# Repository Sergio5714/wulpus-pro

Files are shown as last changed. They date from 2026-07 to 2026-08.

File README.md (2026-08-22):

# WULPUS PRO
## A base platform for wearable ultra-low-power ultrasound
> Independent fork by @Sergio5714 (Sergei Vostrikov)

<p align="center">
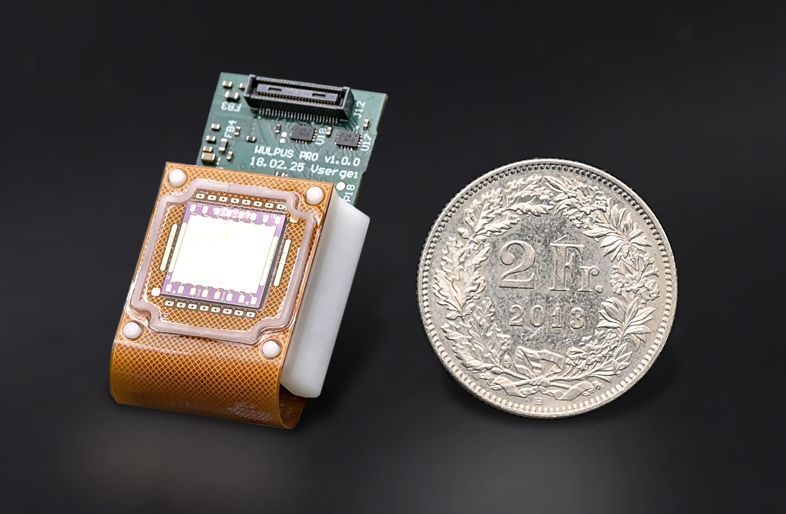
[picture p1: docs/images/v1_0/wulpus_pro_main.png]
WULPUS PRO main
  
  <br/>
  WULPUS PRO module with PolyCMUT transducer.
</p>

## Table of contents

- [Introduction](#introduction)
  - [System diagram](#system-diagram)
  - [Hardware photos](#hardware-photos)
  - [Specifications](#specifications)
- [Clone the repository](#clone-the-repository)
- [Structure of the repository](#structure-of-the-repository)
- [Documentation](#documentation)
- [Build Instructions](#build-instructions)
  - [PCBWay shared projects for WULPUS PCBs](#pcbway-shared-projects-for-wulpus-pcbs)
- [Usage](#usage)
  - [Wi-Fi setup: WULPUS PRO + XIAO ESP32-C6](#wi-fi-setup-wulpus-pro--xiao-esp32-c6)
  - [BLE setup: WULPUS PRO + nRF52 DK (legacy)](#ble-setup-wulpus-pro--nrf52-dk-legacy)
- [Citation](#citation)
- [Changelog](#changelog)
- [Authors](#authors)
- [License](#license)
  - [Limitation of Liability](#limitation-of-liability)

# Introduction

This repository contains the work in progress on the WULPUS PRO ultrasound platform, a successor of the [WULPUS Project](https://github.com/Sergio5714/wulpus). It features +30V unipolar programmable pulser, time-multiplexed multichannel acquisition frontend with TGC, optonal envelope extractor and support of PZTs and CMUTs. The module is compact (40 x 20 mm footprint) and lightweight (5g), allowing integration with external host PCB.

## System diagram

<p align="center">
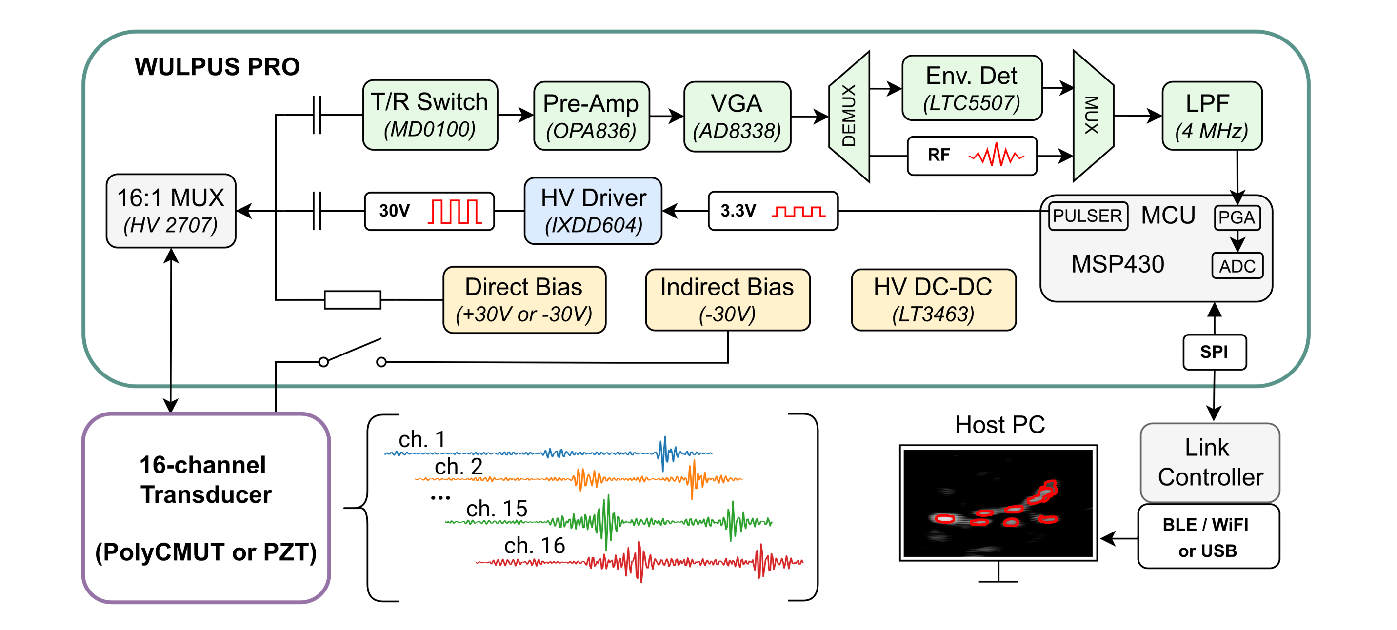
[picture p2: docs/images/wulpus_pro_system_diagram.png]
WULPUS PRO system diagram
  
  <br/>
  WULPUS PRO system diagram
</p>

## Hardware photos

<table>
  <tr>
    <td colspan="2" align="center">
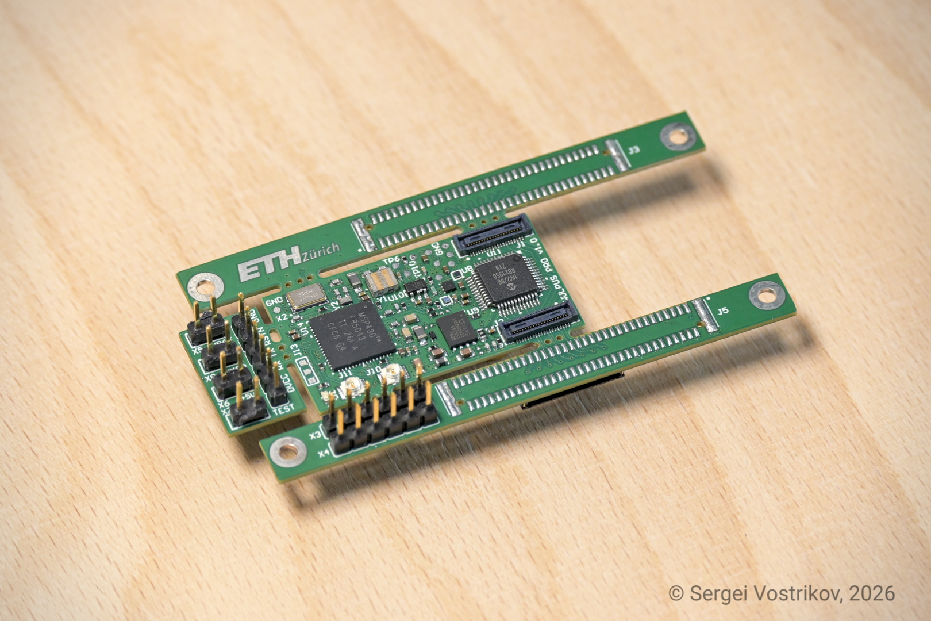
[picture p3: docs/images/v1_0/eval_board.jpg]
WULPUS PRO evaluation board
      
      <br/>
      WULPUS PRO evaluation board
    </td>
  </tr>
  <tr>
    <td width="50%" align="center">
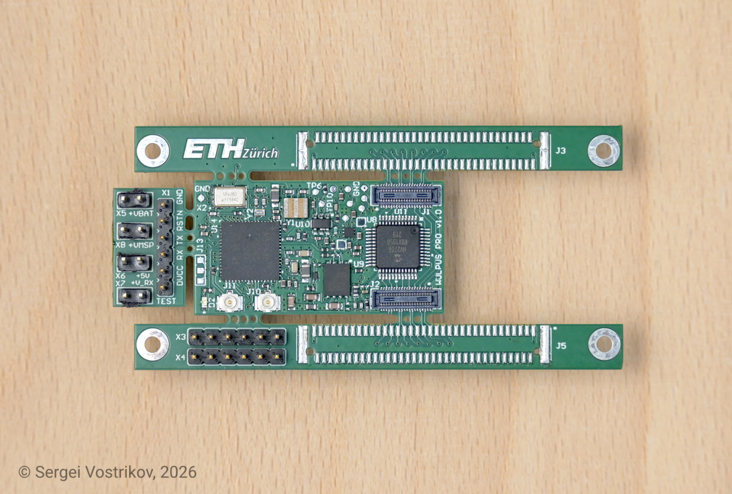
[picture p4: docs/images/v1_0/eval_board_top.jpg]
Top view of the WULPUS PRO evaluation board
      
      <br/>
      Top view
    </td>
    <td width="50%" align="center">
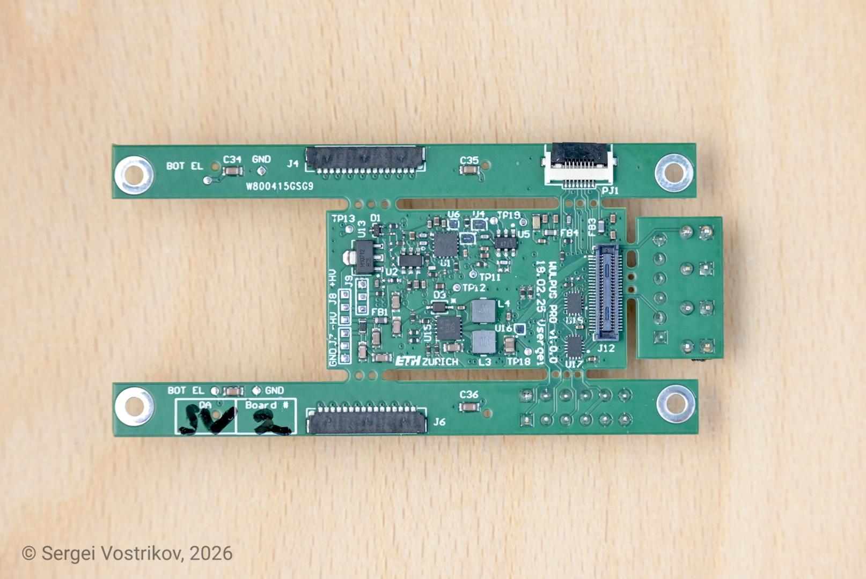
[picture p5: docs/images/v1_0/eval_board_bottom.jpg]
Bottom view of the WULPUS PRO evaluation board
      
      <br/>
      Bottom view
    </td>
  </tr>
</table>

## Specifications

WULPUS PRO builds on the original [WULPUS](https://github.com/Sergio5714/wulpus) platform and keeps the same low-power wearable ultrasound philosophy while extending the hardware and communication options. The table below compares the main features of WULPUS PRO with those of the original WULPUS platform.

| Feature | WULPUS | WULPUS PRO |
| --- | --- | --- |
| Number of channels | 8, time-multiplexed | **16**, time-multiplexed |
| Supported transducers | PZT transducers | PZT transducers, **CMUTs** |
| Excitation amplitude | 15 V unipolar | **30 V** unipolar |
| Excitation frequency | ~100 kHz to 4 MHz | ~100 kHz to **10 MHz** |
| Transducer biasing | - | Indirect or direct **bias**, **-30 V or 30 V** |
| Analog front-end | 10 dB LNA + 30.8 dB PGA | 6 dB LNA + **70 dB VGA** |
| TGC support | No (fixed gain) | **Yes** (linear profile) |
| Maximum PRF | 50 Hz | **300 Hz** |
| Power budget at 50 Hz PRF | <=25 mW | <=40 mW |
| Wireless link | BLE | BLE or **Wi-Fi** (via host) |
| Form factor | 46 x 25 mm footprint | **40 x 20 mm** footprint |

Full WULPUS PRO specifications are available in [docs/full_specifications.md](docs/full_specifications.md).

# Clone the repository

Clone the public repository without its private development submodule:

```bash
git clone git@github.com:Sergio5714/wulpus-pro.git
```

The `hw/kicad_us_lib` submodule is an internal development library hosted in a
private repository. External users do not have access to it and do not need to
initialize it to use the released fabrication outputs. For editing the KiCad
designs, generate project-specific symbol and footprint libraries from the
symbols and footprints embedded in the corresponding project files. See the
[hardware README](hw/README.md#internal-kicad-library) for details.

Authorized developers can initialize the private submodule after cloning:

```bash
git submodule update --init --recursive
```

# Structure of the repository

This repository has the following folders:

- `hw`, containing the CAD source files for:
  - WULPUS PRO acquisition PCB, located at `hw/wulpus_pro_acq_pcb_dev_board`
  - WULPUS PRO Wifi host PCB, located at `hw/wulpus_wifi_host_pcb`
  - optional WULPUS adapter PCB for polyCMUT transducers, located at `hw/wulpus_polycmut_adapter`; this board was developed for research purposes
- `fw`, containing the firmware source code, namely:
  - MSP430 ultrasound MCU firmware required for the WULPUS PRO module, located at `fw/msp430`
  - ESP32 Wi-Fi firmware for the Seeed Studio XIAO ESP32-C6, located at `fw/esp32`
  - nRF52 firmware, located at `fw/nrf52`:
    - nRF52832 DK board firmware, located at `fw/nrf52/ble_peripheral/US_probe_nRF52_firmware`
    - nRF52840 USB dongle firmware, located at `fw/nrf52/peripheral/US_probe_dongle_firmware`
- `sw`, containing the Python code for the WULPUS PRO API and graphical user interface
- `docs`, containing project-level documentation such as the full WULPUS PRO specifications

# Documentation

WULPUS PRO builds on top of the original WULPUS platform. Please refer to the original [WULPUS User Manual](https://github.com/Sergio5714/wulpus/blob/main/docs/wulpus_user_manual.pdf) for assembly instructions, example measurements, and GUI overview.

For WULPUS PRO-specific documentation, see:

- [Full specifications](docs/full_specifications.md)
- [Hardware README](hw/README.md)
- [MSP430 firmware README](fw/msp430/README.md)
- [ESP32 Wi-Fi firmware README](fw/esp32/README.md)
- [nRF52 BLE firmware README](fw/nrf52/README.md)
- [Software README](sw/README.md)

# Build Instructions

To build your own instance of the WULPUS PRO platform, complete the following steps:

1. *PCB manufacturing and assembly*<br>
   Use the design files, schematics, and bills of materials under the `hw` folder. The WULPUS PRO acquisition PCB is required. The polyCMUT adapter PCB is optional and intended for research setups using polyCMUT transducers.

2. *Flash the required MSP430 firmware*<br>
   The MSP430 ultrasound MCU firmware is required for the WULPUS PRO module. Follow the instructions in `fw/msp430` to set up the toolchain, compile the firmware, and flash the MSP430 MCU.

3. *Prepare a host system*<br>
   Choose one of the supported host interfaces:

   - ESP32-based Wi-Fi host, for example the Seeed Studio XIAO ESP32-C6. Follow the instructions in [fw/esp32/README.md](fw/esp32/README.md) to build and flash the ESP32 firmware. After flashing, complete the provisioning step so WULPUS PRO can connect to your Wi-Fi network.
   - nRF52 BLE host, using the nRF52832 DK board and nRF52840 USB dongle. This is the legacy BLE setup. Follow the instructions in [fw/nrf52/README.md](fw/nrf52/README.md) to compile and flash both firmwares.

   > **Note:** The new [WULPUS PRO WiFi host PCB](hw/wulpus_wifi_host_pcb) is currently undergoing testing
   > and will be integrated into the platform soon. It will support standard
   > Adafruit-compatible batteries for operation in WiFi mode, as well as
   > USB-only power and data streaming for WULPUS PRO. Until its integration is
   > complete, please use an external Seeed Studio XIAO ESP32-C6 module.

4. *Python dependencies installation on the host PC*<br>
   Follow the instructions in `sw` to install the Python dependencies. With `uv`, the basic setup is:

   ```bash
   uv sync
   uv run jupyter notebook
   ```

## PCBWay shared projects for WULPUS PCBs

For convenient one-click PCB production and assembly, you can use the PCBWay shared projects (optional; DIY via the `hw` folder is also supported):
- [WULPUS PRO Evaluation Board v1.0.0](https://www.pcbway.com/project/shareproject/WULPUS_PRO_Evaluation_board_v1_0_0_992d7510.html)

This option is convenient for outsourced PCB production and assembly, with an estimated **~1 month lead time** and a price of about **USD 220** per probe (evaluation board), based on mid-2026 pricing.

# Usage

## Wi-Fi setup: WULPUS PRO + XIAO ESP32-C6

1. Connect the ESP32 host module to the WULPUS PRO board using the pin mapping documented in [fw/esp32/README.md](fw/esp32/README.md).
2. Power the ESP32-based host module, for example the Seeed Studio XIAO ESP32-C6 running the firmware from `fw/esp32`.
3. Power the WULPUS PRO board through the connector or debug pin headers.
4. Start Jupyter from the `sw` folder:

   ```bash
   uv run jupyter notebook
   ```

5. Open `wulpus_pro_wifi_example.ipynb` in the browser and follow the notebook instructions for discovery, connection setup, configuration transfer, and acquisition.

## BLE setup: WULPUS PRO + nRF52 DK (legacy)

1. Connect the nRF52 DK to the WULPUS PRO board using the pin mapping documented in [fw/nrf52/README.md](fw/nrf52/README.md).
2. Plug in the USB dongle and power the nRF52 DK via USB.
3. Check the dongle connection. The green LED should light up. If it does not, press the reset button on the nRF52 DK and try again.
4. After confirming dongle connectivity, power the WULPUS PRO board through the connector or debug pin headers.
5. Start Jupyter from the `sw` folder:

   ```bash
   uv run jupyter notebook
   ```

6. Open `wulpus_pro_gui.ipynb` in the browser and follow the notebook instructions to begin acquisition.

# Citation

Please cite our [arXiv preprint](https://arxiv.org/abs/2607.12137):

```bibtex
@article{vostrikov2026wulpuspro,
  title={WULPUS PRO: Multi-mode Ultra-Low-Power Wearable Ultrasound and Array Imaging with CMUT Support},
  author={Vostrikov, Sergei and Villani, Federico and Hirschi, Cedric and Lu, Jinhao and Welsch, Jonas and Angerer, Martin and Cretu, Edmond and Rohling, Robert and Cossettini, Andrea and Benini, Luca},
  journal={arXiv preprint arXiv:2607.12137},
  year={2026},
  url={https://arxiv.org/abs/2607.12137}
}
```

If you would like to cite this repository, please use:

```bibtex
@misc{wulpus_pro_repo_sergio5714_2026,
  title={WULPUS PRO: A Base Platform for Wearable Ultra-Low-Power Ultrasound (Independent Fork)},
  author={Vostrikov, Sergei and Villani, Federico and Hirschi, Cedric and Cossettini, Andrea and Benini, Luca},
  year={2026},
  howpublished={GitHub repository},
  url={https://github.com/Sergio5714/wulpus-pro}
}
```

# Changelog

See [CHANGELOG.md](CHANGELOG.md) for release notes and main project changes.

# Authors

This fork is maintained independently by @Sergio5714 ([Sergei Vostrikov](https://scholar.google.com/citations?user=a0KNUooAAAAJ&hl=en)).

The WULPUS PRO system was originally developed at the [Integrated Systems Laboratory (IIS)](https://iis.ee.ethz.ch/) at ETH Zurich by:

- [Sergei Vostrikov](https://scholar.google.com/citations?user=a0KNUooAAAAJ&hl=en) (PCB design, firmware, software, open-sourcing)
- [Federico Villani](https://scholar.google.com/citations?user=5LgLMCEAAAAJ&hl=en) (PCB design, component selection)
- [Cedric Hirschi](https://www.linkedin.com/in/c%C3%A9dric-cyril-hirschi-09624021b/) (firmware, software)
- [Andrea Cossettini](https://scholar.google.com/citations?user=d8O91jIAAAAJ&hl=en) (supervision, project administration)
- [Luca Benini](https://scholar.google.com/citations?hl=en&user=8riq3sYAAAAJ) (supervision, project administration)

Thanks to all the people who contributed to the WULPUS PRO platform:

- [Sebastian Frey](https://scholar.google.com/citations?user=7jhiqz4AAAAJ&hl=en), ETH Zürich (design review)
- [Alfonso Blanco Fontao](https://www.linkedin.com/in/alfonso-blanco-fontao-b6214726/), ETH Zürich (design review, PCB fabrication coordination)
- [Ciara Giles Doran](https://www.linkedin.com/in/ciaragilesdoran/) (preliminary evaluation of the AD8338 VGA)

# License

The following files are released under Apache License 2.0 (`Apache-2.0`) (see `sw/LICENSE`):

- `sw/`

The hardware designs are released under Solderpad v0.51 (`SHL-0.51`):

- `hw/`

See the [hardware license table](hw/README.md#license) for the applicable license file and copyright holder for each PCB design.

The `fw/msp430/`, `fw/nrf52/`, and `fw/esp32/` directories contain third-party sources that come with their own licenses. See the respective folders and source files for the licenses used.

## Limitation of Liability

In no event and under no legal theory, whether in tort (including negligence), contract, or otherwise, unless required by applicable law (such as deliberate and grossly negligent acts) or agreed to in writing, shall any Contributor be liable to You for damages, including any direct, indirect, special, incidental, or consequential damages of any character arising as a result of this License or out of the use or inability to use the Work (including but not limited to damages for loss of goodwill, work stoppage, computer failure or malfunction, or any and all other commercial damages or losses), even if such Contributor has been advised of the possibility of such damages.

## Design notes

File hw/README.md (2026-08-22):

# WULPUS PRO PCB design files

This directory contains the PCB designs used by WULPUS PRO. The source files are
provided in Altium Designer or KiCad format, depending on the board. Where
available, each project also includes PDF schematics and assembly drawings under
`docs`, and production-ready files under `fabrication_outputs`, including bills
of materials, Gerber files, NC drill files, and pick-and-place files.

## Included PCB designs

### WULPUS PRO acquisition board

Directory: [`wulpus_pro_acq_pcb_dev_board`](wulpus_pro_acq_pcb_dev_board)

The main WULPUS PRO ultrasound acquisition and pulser board. This board contains
the transmit and receive signal paths, high-voltage switching, power supplies,
MSP430 control circuitry, and the host interface. The design sources are provided
in Altium Designer format. This board is required to build a WULPUS PRO system.

### WULPUS PRO Wifi host

Directory: [`wulpus_wifi_host_pcb`](wulpus_wifi_host_pcb)

A dedicated wireless host board for WULPUS PRO, based on the Seeed Studio XIAO
ESP32-C6. It connects to the acquisition board and runs the ESP32 firmware in
[`../fw/esp32`](../fw/esp32), providing Wi-Fi control and data transfer. The
design sources are provided in KiCad format, together with fabrication and
assembly outputs.

### polyCMUT adapter board

Directory: [`wulpus_polycmut_adapter`](wulpus_polycmut_adapter)

An optional research adapter for connecting polyCMUT transducers to WULPUS. The
design sources are provided in Altium Designer format. This board is not required
for standard WULPUS PRO operation.

## Internal KiCad library

The [`kicad_us_lib`](kicad_us_lib) directory is referenced as a Git submodule and
contains the internal KiCad symbols, footprints, and related library assets used
to develop the hardware designs. It is hosted in a private repository and is
intended only for internal development; external users will not have access to
it. The library could not be made publicly open source because some of its
contents are subject to third-party licensing restrictions.

The released KiCad projects embed the symbols and footprints used by each
design. External users are advised to generate their own project-specific symbol
and footprint libraries from the corresponding project files instead of relying
on `kicad_us_lib`. The released fabrication outputs can be used without the
private submodule.

## PCBWay shared projects

For convenient one-click PCB production and assembly, you can use the PCBWay shared projects (optional; DIY using the design and fabrication files in this folder is also supported):

- [WULPUS PRO Evaluation Board v1.0.0](https://www.pcbway.com/project/shareproject/WULPUS_PRO_Evaluation_board_v1_0_0_992d7510.html)

This option is convenient for outsourced PCB production and assembly, with an estimated **~1 month lead time** and a price of about **USD 220** per probe (evaluation board), based on mid-2026 pricing.

## License

All three PCB designs are released under the Solderpad Hardware License v0.51
(`SHL-0.51`). They use separate license files because their copyright holders
differ:

| PCB design | Directory | License file | Copyright |
| --- | --- | --- | --- |
| WULPUS PRO acquisition board | [`wulpus_pro_acq_pcb_dev_board`](wulpus_pro_acq_pcb_dev_board) | [`LICENSE_ETH`](LICENSE_ETH) | Copyright (C) 2025 ETH Zurich. All rights reserved. |
| WULPUS polyCMUT adapter | [`wulpus_polycmut_adapter`](wulpus_polycmut_adapter) | [`LICENSE_ETH`](LICENSE_ETH) | Copyright (C) 2025 ETH Zurich. All rights reserved. |
| WULPUS PRO Wifi host | [`wulpus_wifi_host_pcb`](wulpus_wifi_host_pcb) | [`LICENSE`](LICENSE) | Copyright (C) 2026 Sergei Vostrikov. All rights reserved. |

The license terms are otherwise identical. The internal `kicad_us_lib`
submodule contains third-party material and is not covered by this table; its
contents retain their respective license terms.

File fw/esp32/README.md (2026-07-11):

# WULPUS PRO source files for ESP32 firmware project

This firmware enables WULPUS PRO to connect to Wi-Fi via a ESP32-C6, which enables higher throughputs and thus framerates.

The firmware includes the following features:
- **mDNS**: Multicast DNS for local network discovery
- **Full integration with the Python API**: The firmware also comes with an extension to the Python API, which allows you to control the WULPUS PRO over Wi-Fi
- **Power Management**: The firmware includes power management, which allows the ESP32 to enter light sleep when not in use. This results in ~1.5mA current draw
- **Easy expandability**: The firmware is designed to be easily extensible, allowing you to add new features and functionality as needed

# How to get started?

This firmware is written with [ESP-IDF](https://github.com/espressif/esp-idf). We recommend using at the official [VS Code extension](https://github.com/espressif/vscode-esp-idf-extension/tree/master).

The firmware has been tested on both the [ESP32-C6-DEVKITM-1](https://docs.espressif.com/projects/esp-dev-kits/en/latest/esp32c6/esp32-c6-devkitm-1/user_guide.html) and the [Seeed Studio XIAO ESP32-C6](https://wiki.seeedstudio.com/xiao_esp32c6_getting_started/) boards. The XIAO ESP32-C6 target is expected to receive longer-term support, while the DevKit remains useful for development and bring-up. The firmware should work on other ESP32-C6 boards with suitable board defaults, and is designed to be portable to other ESP32 boards as well.

### Board Variants

Board-specific pinouts are stored as ESP-IDF defaults files under `boards/`. Keep reusable project settings in `sdkconfig.defaults`, chip-level settings in `sdkconfig.defaults.<target>`, and board pin choices in the board file.

To configure the firmware for the Seeed Studio XIAO ESP32-C6:

```powershell
idf.py -D SDKCONFIG_DEFAULTS="sdkconfig.defaults;sdkconfig.defaults.esp32c6;boards/xiao-esp32c6.defaults" reconfigure
```

To configure the firmware for the ESP32-C6-DEVKITM-1:

```powershell
idf.py -D SDKCONFIG_DEFAULTS="sdkconfig.defaults;sdkconfig.defaults.esp32c6;boards/esp32c6-devkitm-1.defaults" reconfigure
```

After reconfiguring, build and flash as usual:

```powershell
idf.py build
idf.py -p COM7 flash monitor
```

Adapt `COM7` to the serial port assigned to your ESP32 board.

### IMPORTANT: Provision Wi-Fi after flashing

After flashing the firmware for the first time, provision the ESP32-C6 with the Wi-Fi network credentials. Provisioning lets the ESP32 store the SSID and password in non-volatile memory, so the firmware can reconnect to the same network after reset or power cycling.

Follow Espressif's provisioning documentation for the first-time setup flow: [ESP-IDF Provisioning API](https://docs.espressif.com/projects/esp-idf/en/stable/esp32c6/api-reference/provisioning/index.html).

### Connection to WULPUS PRO

Use the following default pin mappings to connect the WULPUS PRO acquisition board to the ESP32-C6 board.

Seeed Studio XIAO ESP32-C6:

| **Signal** | **ESP32-C6 GPIO** | **XIAO ESP32-C6 Pin** | **WULPUS PRO Connector Pin** |
|---|---|---|---|
| `SPI_SS` | 21 | D3 | X3.4 |
| `SPI_CLK` | 19 | D8 / SCK | X3.3 |
| `SPI_MISO` | 20 | D9 / MISO | X3.1 |
| `SPI_MOSI` | 18 | D10 / MOSI | X3.2 |
| `Data_ready` | 1 | D1 | X4.2 |
| `BLE_conn_ready` | 0 | D0 | X4.3 |
| `MSP_RST_N` | 2 | D2 | X1.5 |

ESP32-C6-DEVKITM-1:

| **Signal** | **ESP32-C6 GPIO** | **DevKit Header Name** | **WULPUS PRO Connector Pin** |
|---|---|---|---|
| `SPI_SS` | 18 | 18 | X3.4 |
| `SPI_CLK` | 6 | 6 | X3.3 |
| `SPI_MISO` | 7 | 7 | X3.1 |
| `SPI_MOSI` | 2 | 2 | X3.2 |
| `Data_ready` | 1 | 1/N | X4.2 |
| `BLE_conn_ready` | 0 | 0/N | X4.3 |
| `MSP_RST_N` | 3 | 3 | X1.5 |

For the ESP32-C6-DEVKITM-1 defaults, GPIO2 is used for `SPI_MOSI`; `MSP_RST_N` is therefore mapped to GPIO3.

On the XIAO ESP32-C6 side headers shown in the board pinout, the exposed SPI-labeled pins are `D10`/GPIO18 (`MOSI`), `D9`/GPIO20 (`MISO`), and `D8`/GPIO19 (`SCK`). Chip select uses `D3`/GPIO21.
`MSP_RST_N` is configured as an open-drain active-low output without an internal pull-up. It is asserted low while no TCP client is connected, released high after a TCP client connects, and held for 100 ms before command handling continues. It is asserted low again when the TCP connection closes or is lost.

For a new board revision, copy one of the files in `boards/`, change only the `CONFIG_WP_*` and board hardware values, then pass that file in `SDKCONFIG_DEFAULTS`.

### Python Wi-Fi Example

For Python-side usage, see the Wi-Fi example notebook at `../../sw/wulpus_pro_wifi_example.ipynb`. It shows device discovery, connection setup with `WulpusWiFi`, configuration transfer, and data acquisition over the TCP link.

# Authors

- Cedric Hirschi, ETH Zurich
- Sergei Vistrikov (Sergio5714 on GitHub)

# License

ESP-IDF is licensed under the Apache License 2.0. See the [LICENSE](https://github.com/espressif/esp-idf/blob/master/LICENSE) in the ESP-IDF repository for more information.

ESP-IDF uses multiple third-party components, which are licensed under various other open-source licenses. One example is [FreeRTOS](https://github.com/FreeRTOS). Please make sure all of the licenses are compatible with your project.

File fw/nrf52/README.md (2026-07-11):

# WULPUS PRO source files for nRF52 DK BLE MCU firmware projects
This directory contains the source files for 
- nRF52832 BLE MCU (`fw/nrf52/ble_peripheral`) used by nRF52 DK.
- nRF52840 Dongle (`fw/nrf52/peripheral`) used to receive the ultrasound data on a host PC.

# How to get started?

Please refer to the `WULPUS User Manual` of the WULPUS system v 1.2.2 for the instructions on how to flash the BLE MCU and USB Dongle:
`https://github.com/Sergio5714/wulpus/blob/main/docs/wulpus_user_manual.pdf`

### Interconnect with nRF52 DK

Use the following pin mapping to connect the WULPUS PRO acquisition board to the **nRF52 DK**:

| **Signal** | **nRF52 DK Pin** | **WULPUS PRO Connector Pin** |
|---|---|---|
| `SPI_SS` | P0.04 | X3.4 |
| `SPI_CLK` | P0.29 | X3.3 |
| `SPI_MISO` | P0.30 | X3.1 |
| `SPI_MOSI` | P0.31 | X3.2 |
| `Data_ready` | P0.24 | X4.2 |
| `BLE_conn_ready` | P0.25 | X4.3 |

# License
The files in the `fw/nrf52/ble_peripheral` and `fw/nrf52/peripheral` directories contain third-party sources that come with their own licenses. See the respective folders and source files' headers for the licenses used.

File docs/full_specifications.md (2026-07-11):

# WULPUS PRO Full Specifications

## Transducer and transmit path

| Feature | Specification |
| --- | --- |
| Channels | 16, time-multiplexed |
| Transducer support | PZT transducers and CMUTs |
| Transducer bias | Indirect or direct bias, -30 V or 30 V |
| Excitation amplitude | 30 V unipolar |
| Excitation frequency | 100 kHz to 10 MHz |

## Receive path

| Feature | Specification |
| --- | --- |
| Analog front-end | 6 dB LNA + 70 dB VGA |
| Time gain compensation | TGC up to 70 dB depth-dependent attenuation compensation |
| Envelope extraction | Optional LTC5507-based envelope detector, runtime configurable |
| Envelope detector bandwidth | Up to 1.5 MHz envelope bandwidth |
| Amplification-path bandwidth | 9.9 MHz |
| End-to-end -3 dB bandwidth | 1.4 MHz (bounded by MSP430) |
| Usable measured bandwidth | SNR >=10 dB up to 2.5 MHz |
| Passband SNR | Approximately 32 dB at 40 dB total gain |
| Peak SINAD | 41.42 dB (1 MHz), 36.25 dB (2.25 MHz), both at 4.9 mV input amplitude |
| ENOB | ~7.8 bits |

## Acquisition and data link

| Feature | Specification |
| --- | --- |
| ADC | 8 Msps analog-to-digital converter, 12-bit resolution |
| Host interface | SPI, 8 MHz |
| Maximum PRF | 300 Hz |
| Raw streaming over BLE | 50 Hz PRF |
| Raw streaming over Wi-Fi | Up to 300 Hz PRF |

## Power

| Feature | Specification |
| --- | --- |
| Power budget | <=40 mW at 50 Hz PRF |
| Core electronics power | 35 mW (50 Hz PRF), 58 mW (300 Hz PRF) |
| Battery-life reference | More than 24 hours of continuous raw data streaming at 50 Hz PRF from a 300 mAh Li-Po battery with BLE |

## Imaging performance

| Feature | Specification |
| --- | --- |
| B-mode frame rate | 18 FPS using 16-channel synthetic-aperture acquisition at 300 Hz PRF |
| B-mode axial resolution | ~ 0.7 mm with a 2.25 MHz transducer (LA-2.25-32, Vermon) |
| B-mode lateral resolution | ~ 2.3 mm at the center with a 2.25 MHz transducer (LA-2.25-32, Vermon) |

## Mechanics

| Feature | Specification |
| --- | --- |
| Module size | 39 x 21 x 6 mm |
| Weight | 5 g |

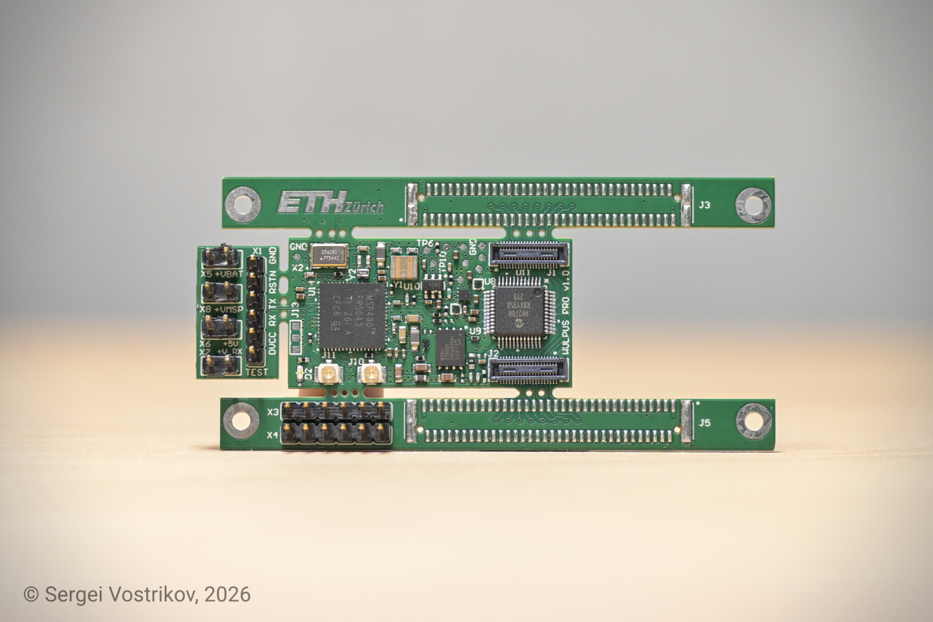
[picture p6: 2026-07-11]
docs/images/v1_0/eval_board_main.jpg

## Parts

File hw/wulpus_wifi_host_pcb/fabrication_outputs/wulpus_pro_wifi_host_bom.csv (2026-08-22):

Reference | Qty | Value | Exclude from BOM | MANUFACTURER | MP
C1,C2,C5,C6 | 4 | 22 uF |  | Murata Electronics | GRM187R60J226ME15
C3,C7,C9,C10 | 4 | 10 uF |  | Murata Electronics | GRM188R61A106ME69
C4,C8 | 2 | 100 nF |  | Murata Electronics | GCM155R71H104KE02J
D1 | 1 | LMBR4010BST5G |  | LRC | LMBR4010BST5G
J1 | 1 | S2B-PH-SM4-TB_LF__SN_ |  | JST | S2B-PH-SM4-TB(LF)(SN)
J2 | 1 | DF40C-50DP-0.4V_51_ |  | Hirose Electric Co Ltd | DF40C-50DP-0.4V(51)
L1,L2 | 2 | DFE201612E-2R2M=P2 |  | Murata Electronics | DFE201612E-2R2M=P2
Q1 | 1 | FS8205A |  | FUXINSEMI | FS8205A
Q2 | 1 | LP0404N3T5G |  | LRC | LP0404N3T5G
R1,R2,R3,R4,R5,R6,R7,R8,R9,R10,R11 | 11 | 47 |  | Yageo | RC0402FR-1347RL
R12,R13,R18,R20 | 4 | 0 |  | Yageo | RC0402JR-070RL
R14 | 1 | 2.2k |  | Yageo | RC0402FR-072K2L
R15 | 1 | 16.2k |  | Yageo | RC0402FR-0716K2L
R16,R17 | 2 | 5.1M |  | Yageo | RC0402FR-075M1L
R19 | 1 | 330 |  | Yageo | RC0402FR-07330RL
R21 | 1 | 36.5k |  | Yageo | RC0402FR-0736K5L
R22 | 1 | 100k |  | Yageo | RC0402FR-07100KL
R23 | 1 | 100 |  | Yageo | RC0402FR-07100RL
U1 | 1 | XIAO-ESP32-C6-SMD |  | Seeed Studio | XIAO ESP32C6
U2,U4 | 2 | TPS63900DSKR |  | Texas Instruments | TPS63900DSKR
U3 | 1 | BQ29700DSER |  | Texas Instruments | BQ29700DSER

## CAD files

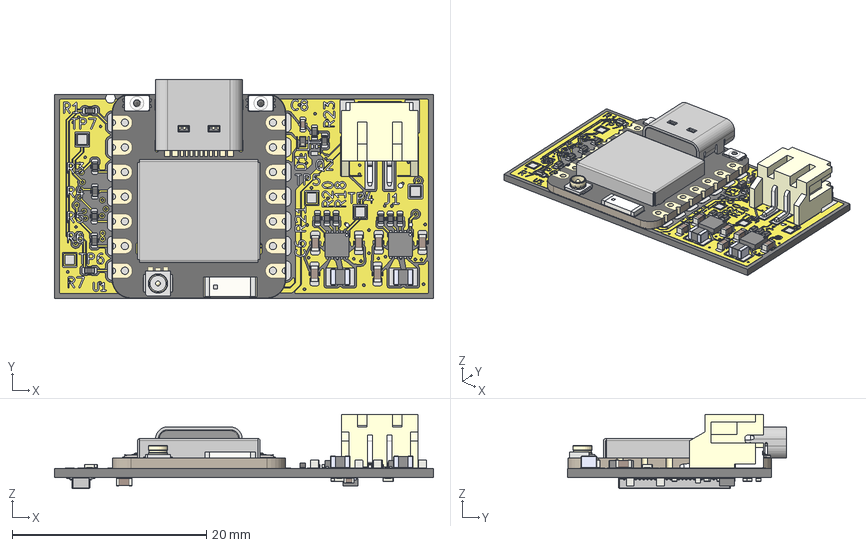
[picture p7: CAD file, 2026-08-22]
hw/wulpus_wifi_host_pcb/docs/wulpus_pro_wifi_host.step
39.0 x 22.5 x 7.65 mm
R_0402_1005Metric x 23
DFE201612R-H-1R0M=P2 x 2
C_0603_1608Metric x 8
D_SOD-882
C_0402_1005Metric x 2
TPS7A9201DSKT x 2
BOSS-EXTRUDE14_8_
BOSS-EXTRUDE7_4_
BOSS-EXTRUDE7_3_
BOSS-EXTRUDE14_4_
BOSS-EXTRUDE14_2_
BOSS-EXTRUDE14_11_
BOSS-EXTRUDE7_7_
BOSS-EXTRUDE14_9_
BOSS-EXTRUDE14_3_
BOSS-EXTRUDE14_7_
MIRROR2
BOSS-EXTRUDE14_5_
BOSS-EXTRUDE14_12_
BOSS-EXTRUDE7_8_
BOSS-EXTRUDE7_1_
BOSS-EXTRUDE14_10_
BOSS-EXTRUDE7_9_
BOSS-EXTRUDE14_6_
BOSS-EXTRUDE14_1_
BOSS-EXTRUDE7_6_
BOSS-EXTRUDE7_2_
CUT-EXTRUDE5
BOSS-EXTRUDE7_5_
U.FL Connector v1
Shield
SKTAAAE010 v1 x 2
KH5220-A36 (Ceramic Antenna) v2
S2B-PH-SM4-TB(LF)(SN)
DSE6
DF40C-40DP-0.4V.1
wulpus_pro_wifi_host_copper
wulpus_pro_wifi_host_pad
wulpus_pro_wifi_host_via
wulpus_pro_wifi_host_silkscreen x 2
wulpus_pro_wifi_host_PCB

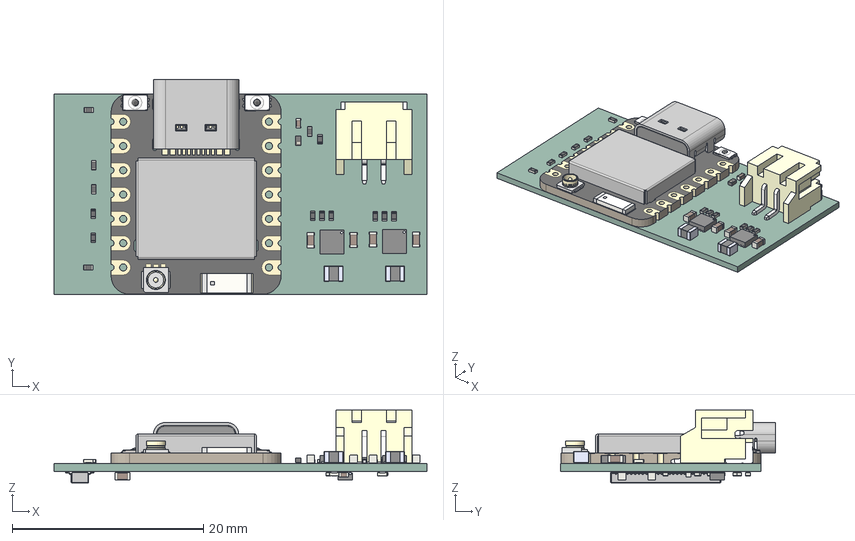
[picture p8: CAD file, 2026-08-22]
hw/wulpus_wifi_host_pcb/wulpus_pro_host.step
39.0 x 22.5 x 7.60 mm
R_0402_1005Metric x 23
DFE201612R-H-1R0M=P2 x 2
D_SOD-882
C_0402_1005Metric x 2
C_0603_1608Metric x 6
TPS7A9201DSKT x 2
BOSS-EXTRUDE14_8_
BOSS-EXTRUDE7_4_
BOSS-EXTRUDE7_3_
BOSS-EXTRUDE14_4_
BOSS-EXTRUDE14_2_
BOSS-EXTRUDE14_11_
BOSS-EXTRUDE7_7_
BOSS-EXTRUDE14_9_
BOSS-EXTRUDE14_3_
BOSS-EXTRUDE14_7_
MIRROR2
BOSS-EXTRUDE14_5_
BOSS-EXTRUDE14_12_
BOSS-EXTRUDE7_8_
BOSS-EXTRUDE7_1_
BOSS-EXTRUDE14_10_
BOSS-EXTRUDE7_9_
BOSS-EXTRUDE14_6_
BOSS-EXTRUDE14_1_
BOSS-EXTRUDE7_6_
BOSS-EXTRUDE7_2_
CUT-EXTRUDE5
BOSS-EXTRUDE7_5_
U.FL Connector v1
Shield
SKTAAAE010 v1 x 2
KH5220-A36 (Ceramic Antenna) v2
S2B-PH-SM4-TB(LF)(SN)
DSE6
DF40C-40DP-0.4V.1
wulpus_pro_wifi_host_PCB

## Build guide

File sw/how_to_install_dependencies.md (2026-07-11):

# How to install Python requirements

The software project uses `uv` for Python dependency management.

1. Install `uv`: https://docs.astral.sh/uv/getting-started/installation/
2. Open a terminal in the `sw` folder.
3. Create the local environment and install dependencies:

```bash
uv sync
```

4. Start Jupyter from the same folder:

```bash
uv run jupyter notebook
```

5. Open the required notebook in the browser, for example `wulpus_pro_gui.ipynb` or `wulpus_pro_wifi_example.ipynb`, and follow the notebook instructions.

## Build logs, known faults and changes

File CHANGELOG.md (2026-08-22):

# Changelog

All main changes to this project will be documented in this file.
For the detailed description, please explore nested folders and corresponding CHANGELOG.md files (e.g. for PCB projects or firmware). 

The format is based on [Keep a Changelog](https://keepachangelog.com/en/1.0.0/),
and this project adheres to [Semantic Versioning](https://semver.org/spec/v2.0.0.html).

## [1.1.0] - 2026-08-22
1
### Added

- Added the WULPUS PRO Wifi host PCB design (KiCad) and fabrication outputs.
- Added board-specific hardware licensing documentation and a separate `hw/LICENSE_ETH` file for the ETH Zurich PCB designs.
- Expanded the hardware README with the represented PCB designs, their CAD formats, purposes, and license assignments.
- Documented the WULPUS PRO Wifi host PCB testing status, planned battery and USB operating modes, and temporary use of an external XIAO ESP32-C6.
- Documented that `kicad_us_lib` is a private, development-only submodule and advised external users to generate project-specific KiCad libraries from the project files.
- Added the `kicad_us_lib` repository as a Git submodule under `hw/kicad_us_lib`.
- Added private-submodule cloning guidance for maintainers and external users to the root README.
- Added a linked table of contents to the root README.
- Added the WULPUS PRO arXiv preprint citation and BibTeX entry to the root README.
- Added PCBWay shared-project production and assembly information to the hardware README.
- Expanded the root README acknowledgements.

## [1.0.0] - 2026-07-11

### Added

- Added ESP32-C6 Wi-Fi firmware support for the Seeed Studio XIAO ESP32-C6 board, including board-specific defaults and README pin mapping.
- Added MSP430 board reset control logic to the ESP32 Wi-Fi firmware.
- Added a Python Wi-Fi example notebook for discovery, connection setup, configuration transfer, and data acquisition over the ESP32 TCP link.
- Added Apache-2.0 license headers to ESP32 firmware source files and Python support scripts.
- Added a documentation changelog under `docs/`.
- Added image documentation README with CC BY-ND 4.0 license information.
- Added WULPUS PRO images to the root README hero and hardware photos sections.
- Added the WULPUS PRO system diagram to the root README.
- Added `uv` project metadata and lockfile for Python dependency management.
- Added a root README specifications section comparing WULPUS PRO with the original WULPUS platform.

### Fixed

- Fixed the MSP430 firmware initialization so the preamplifier power switch is always enabled at startup.
- Fixed the ESP32-C6-DEVKITM-1 board defaults to avoid reusing GPIO2 for both SPI MOSI and MSP430 reset.

### Changed

- Refactored the ESP32 firmware configuration around reusable ESP-IDF defaults, target-specific defaults, and board-specific pinout files.
- Updated the ESP32 project from ESP-IDF 5.4.1 to ESP-IDF 6.0.1.
- Updated ESP32 documentation for tested DevKit and XIAO boards, board selection, flashing, serial port selection, and WULPUS PRO connector pin mappings.
- Updated ESP32 firmware attribution with author information and ESP-IDF example note.
- Reworked the root README introduction with a concise overview of the pulser, acquisition front end, supported transducers, and module form factor.
- Updated project READMEs for repository structure, build instructions, usage flows, firmware links, and WULPUS PRO-specific documentation pointers.
- Migrated Python package management from conda to uv.
- Moved WULPUS PRO full specifications from the root README into `docs/full_specifications.md`.
- Updated gitignore rules.

### Removed

- Removed the old ESP32-C6-DEVKITM-1 MSP430 reset mapping from GPIO2; GPIO2 is used for SPI MOSI and MSP430 reset is now on GPIO3.
- Removed the old Conda `sw/requirements.yml` dependency file.

## [0.1.0] - 2025-05-1

### Added
- Initial release (without official GitHub release)

### Fixed

### Changed

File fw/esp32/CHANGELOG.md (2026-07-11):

# Changelog

All notable changes to this project will be documented in this file.

The format is based on [Keep a Changelog](https://keepachangelog.com/en/1.0.0/),
and this project adheres to [Semantic Versioning](https://semver.org/spec/v2.0.0.html).

## [Unreleased]

### Added

- Added ESP32-C6 Wi-Fi firmware for using an ESP32 module as a WULPUS PRO host interface.
- Added support for the Seeed Studio XIAO ESP32-C6 board.
- Added board-specific defaults for the Seeed Studio XIAO ESP32-C6 and ESP32-C6-DEVKITM-1.
- Added Wi-Fi provisioning support for storing network credentials in non-volatile memory.
- Added mDNS-based local network discovery.
- Added MSP430 reset control from the ESP32 host firmware.
- Added power-management support for light-sleep operation when idle.
- Added WULPUS PRO connector pin mapping documentation for supported ESP32-C6 boards.
- Added Python-side Wi-Fi usage documentation through `../../sw/wulpus_pro_wifi_example.ipynb`.

### Fixed

- Fixed the ESP32-C6-DEVKITM-1 defaults so `MSP_RST_N` no longer conflicts with SPI MOSI on GPIO2.

### Changed

- Updated the project to ESP-IDF 6.0.1.
- Refactored ESP-IDF configuration into reusable project defaults, target-specific defaults, and board-specific defaults.
- Documented first-time Wi-Fi provisioning after flashing the firmware.
- Documented tested board variants, board selection, build, flash, and serial-port usage.

### Removed

- Removed the old ESP32-C6-DEVKITM-1 reset mapping from GPIO2; `MSP_RST_N` is now mapped to GPIO3 for that board.

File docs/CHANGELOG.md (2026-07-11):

# Changelog

All notable changes to the WULPUS PRO documentation will be documented in this file.

The format is based on [Keep a Changelog](https://keepachangelog.com/en/1.0.0/),
and this project adheres to [Semantic Versioning](https://semver.org/spec/v2.0.0.html).

## [Unreleased]

### Added

- Added WULPUS PRO full specifications as a dedicated documentation page.
- Added project-level documentation changelog.
- Added image documentation README with authorship and CC BY-ND 4.0 license information.
- Added WULPUS PRO images to the root README hero and hardware photos sections.
- Added the WULPUS PRO system diagram to the root README.

### Changed

- Moved the full specifications table from the root README to `docs/full_specifications.md`.

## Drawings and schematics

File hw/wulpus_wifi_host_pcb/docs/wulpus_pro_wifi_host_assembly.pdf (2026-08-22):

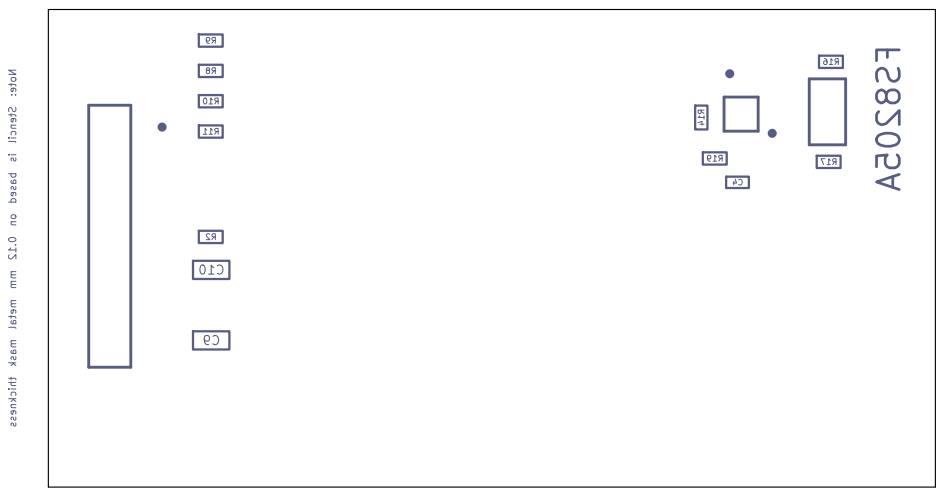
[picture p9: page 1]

Sheet:
File: wulpus_pro_wifi_host.kicad_pcb
Title: WULPUS PRO WiFi host

Size: A4 | Rev: v1.0.0
KiCad E.D.A. 10.0.3 | Id: 1/3

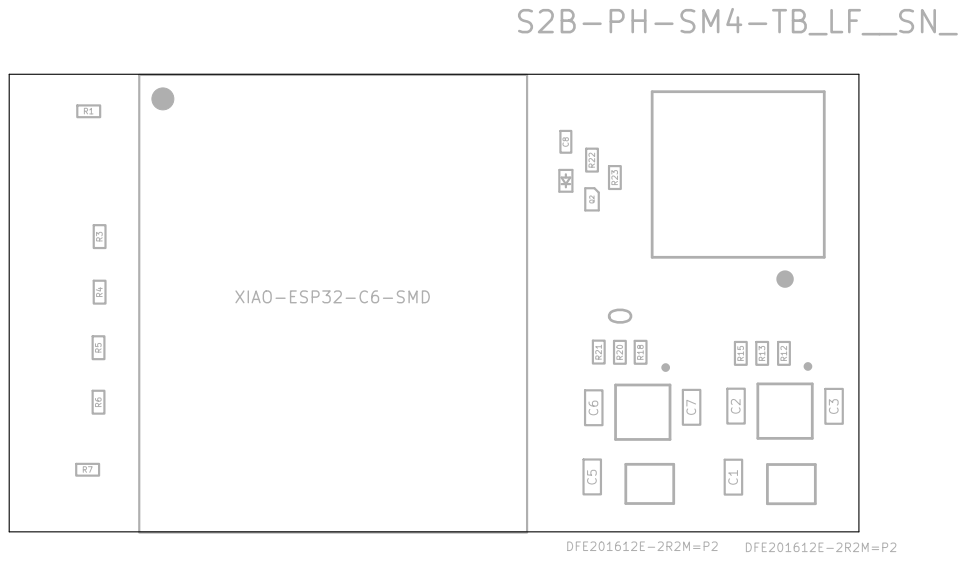
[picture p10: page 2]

Sheet:
File: wulpus_pro_wifi_host.kicad_pcb
Title: WULPUS PRO WiFi host

AB

C

D

AB

C

D Date: 2026-08-22

### Title: WULPUS PRO WiFi host

File: wulpus_pro_wifi_host.kicad_pcb

Sheet:

Reviewer: Cedric Hirshi

Author: Sergei Vostrikov

## BOARD CHARACTERISTICS

Copper layer count: | 4 | Board thickness: | 0.9820 mm
Board overall dimensions: | 39.0000 mm x 21.0000 mm
Min track/spacing: | 0.2000 mm / 0.1400 mm | Min hole diameter: | 0.3000 mm
Copper finish: | None | Impedance control: | No
Castellated pads: | No | Press-fit pads: | No
Plated board edge: | No | Edge card connectors: No
Layer Name | Type | Material | Thickness | Color | Epsilon R | Loss Tangent
F.Silkscreen | Top silk screen | Not specified | Not specified | White | 1 | 0
F.Paste | Top solder paste | | Not specified | | 1 | 0
F.Mask | Top solder mask | Not specified | 0.01 mm | Black | 3.3 | 0
F.Cu | Copper | | 0.035 mm | | 1 | 0
Dielectric 1 | Prepreg | S1000HB | 0.196 mm | Not specified | 4.74 | 0.02
In1.Cu | Copper | | 0.035 mm | | 1 | 0
Dielectric 2 | Core | S1000H | 0.43 mm | Not specified | 4.6 | 0.02
In2.Cu | Copper | | 0.035 mm | | 1 | 0
Dielectric 3 | Prepreg | S1000HB | 0.196 mm | Not specified | 4.74 | 0.02
B.Cu | Copper | | 0.035 mm | | 1 | 0
B.Mask | Bottom solder mask | Not specified | 0.01 mm | Black | 3.3 | 0
B.Paste | Bottom solder paste | | Not specified | | 1 | 0
B.Silkscreen | Bottom silk screen | Not specified | Not specified | White | 1 | 0

39 21

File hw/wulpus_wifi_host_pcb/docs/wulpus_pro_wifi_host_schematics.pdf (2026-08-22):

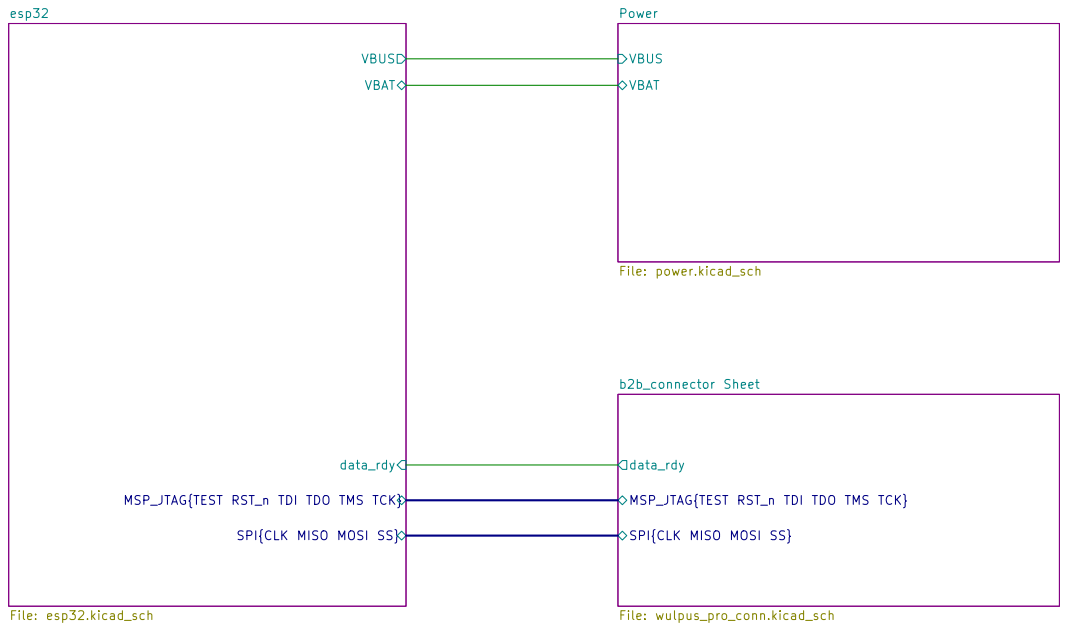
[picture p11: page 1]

esp32
data_rdy VBAT SPI{CLK MISO MOSI SS}

VBAT VBUS Power File: power.kicad_sch

MSP_JTAG{TEST RST_n TDI TDO TMS TCK} VBUS

MSP_JTAG{TEST RST_n TDI TDO TMS TCK}

SPI{CLK MISO MOSI SS}

Sheet: /
File: wulpus_pro_wifi_host.kicad_sch
Title: WULPUS PRO WiFi host

Size: A4 | Rev: v1.0.0
KiCad E.D.A. 10.0.3 | Id: 1/4

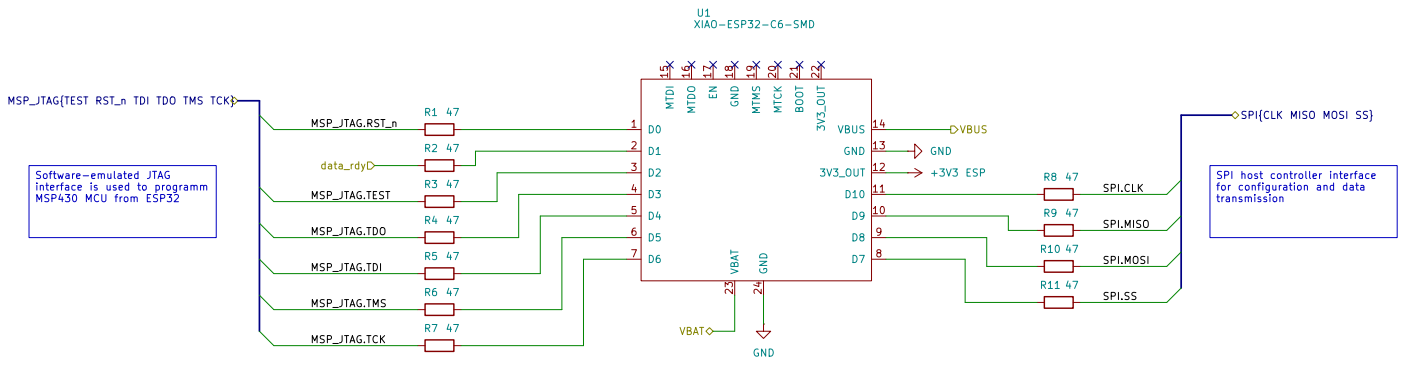
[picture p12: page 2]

VBUS MSP_JTAG{TEST RST_n TDI TDO TMS TCK}

transmission Software-emulated JTAG
interface is used to programm
MSP430 MCU from ESP32

for configuration and data

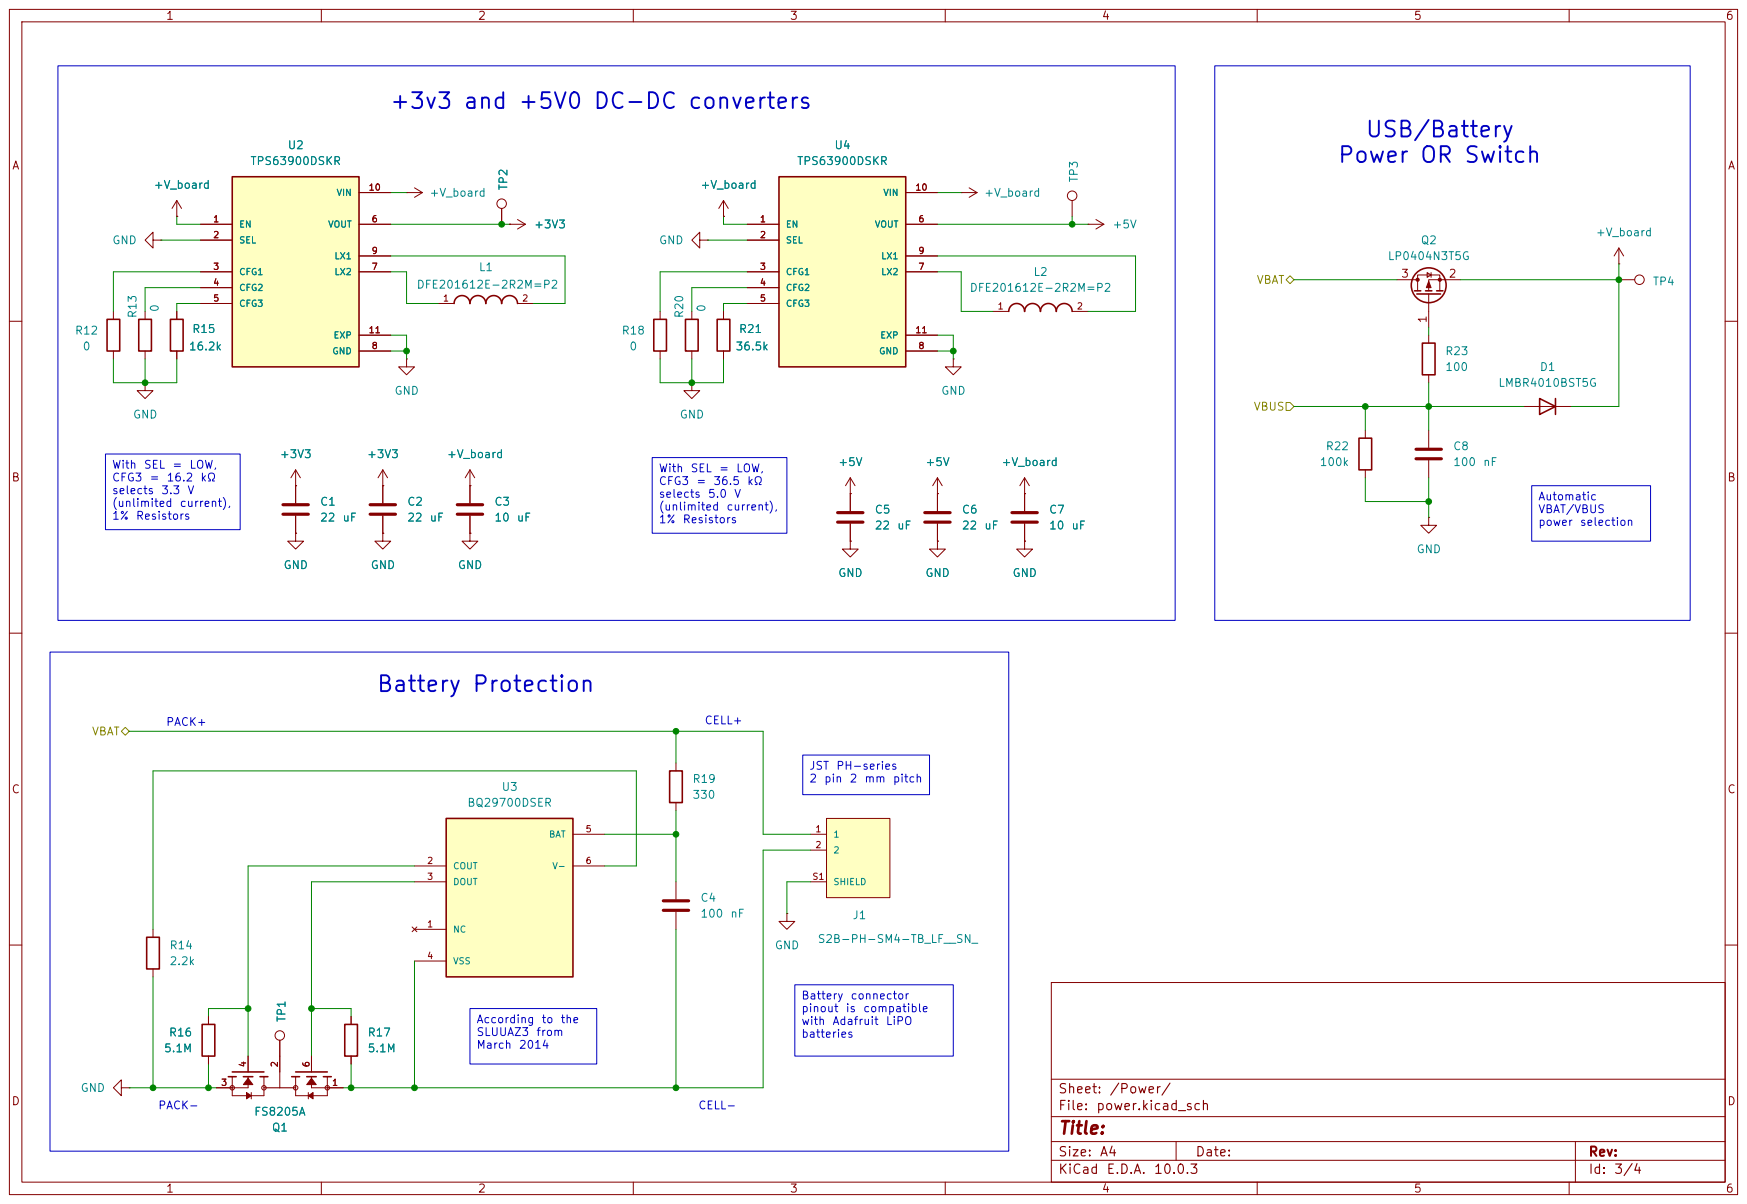
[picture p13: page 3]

(unlimited current), 1% Resistors With SEL = LOW, CFG3 = 16.2 kΩ

power selection With SEL = LOW, CFG3 = 36.5 kΩ

JST PH-series 2 pin 2 mm pitch

Battery connector pinout is compatible with Adafruit LiPO

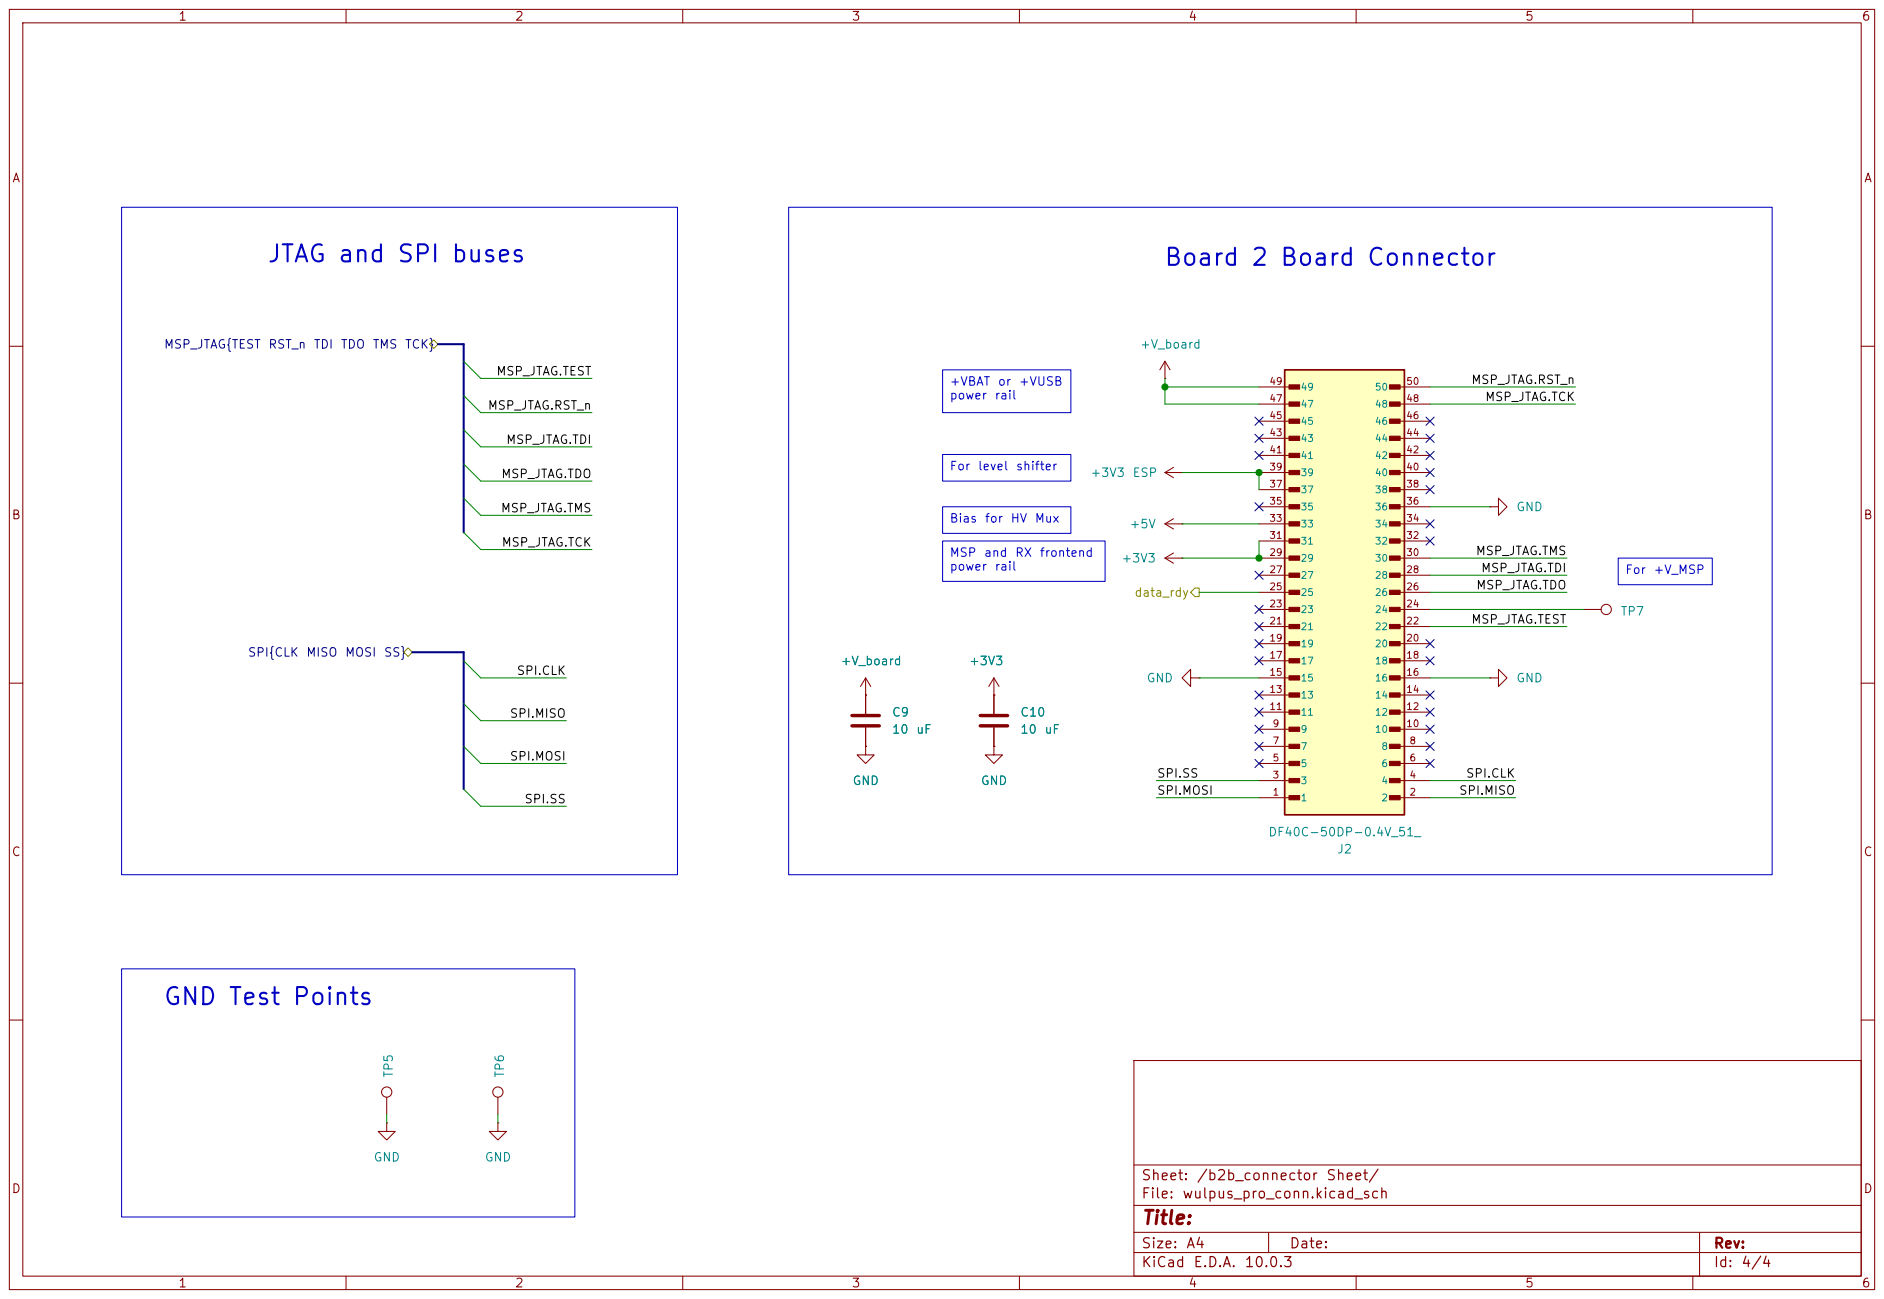
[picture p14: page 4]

power rail JTAG and SPI buses

MSP_JTAG{TEST RST_n TDI TDO TMS TCK}

SPI.CLK MSP_JTAG.TCK MSP_JTAG.TDO

For level shifter Bias for HV Mux MSP and RX frontend

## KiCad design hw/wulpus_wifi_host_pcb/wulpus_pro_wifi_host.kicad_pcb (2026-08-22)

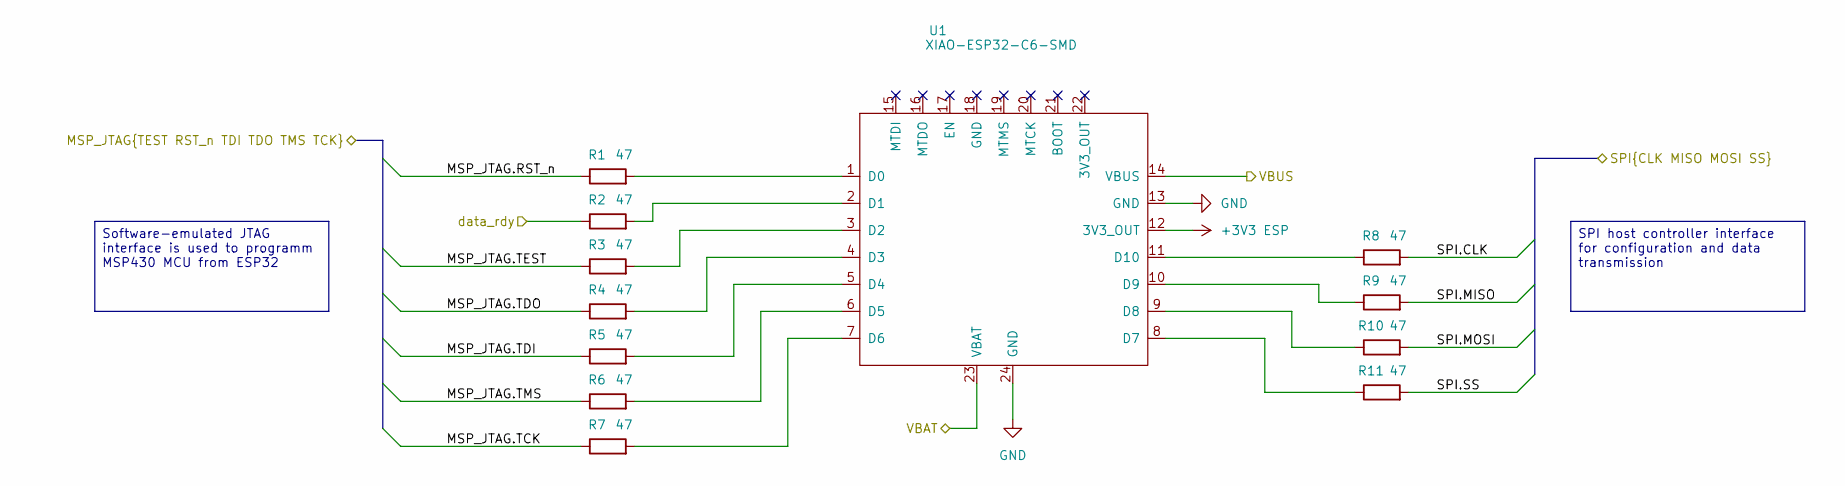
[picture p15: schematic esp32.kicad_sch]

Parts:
R1, R2, R3, R4, R5, R6, R7, R8, R9, R10, R11: 47; R_0402_1005Metric
U1: XIAO-ESP32-C6-SMD

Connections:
+3V3 ESP: U1.12 (3V3_OUT); also elsewhere on the board
/Power/VBAT: U1.23 (VBAT); also elsewhere on the board
/Power/VBUS: U1.14 (VBUS); also elsewhere on the board
/b2b_connector Sheet/MSP_JTAG.RST_n: R1.1; also elsewhere on the board
/b2b_connector Sheet/MSP_JTAG.TCK: R7.1; also elsewhere on the board
/b2b_connector Sheet/MSP_JTAG.TDI: R5.1; also elsewhere on the board
/b2b_connector Sheet/MSP_JTAG.TDO: R4.1; also elsewhere on the board
/b2b_connector Sheet/MSP_JTAG.TEST: R3.1; also elsewhere on the board
/b2b_connector Sheet/MSP_JTAG.TMS: R6.1; also elsewhere on the board
/b2b_connector Sheet/SPI.CLK: R8.2; also elsewhere on the board
/b2b_connector Sheet/SPI.MISO: R9.2; also elsewhere on the board
/b2b_connector Sheet/SPI.MOSI: R10.2; also elsewhere on the board
/b2b_connector Sheet/SPI.SS: R11.2; also elsewhere on the board
/b2b_connector Sheet/data_rdy: R2.1; also elsewhere on the board
GND: U1.13 (GND), U1.24 (GND); also elsewhere on the board
unnamed: R1.2, U1.1 (D0)
unnamed: R2.2, U1.2 (D1)
unnamed: R3.2, U1.3 (D2)
unnamed: R4.2, U1.4 (D3)
unnamed: R5.2, U1.5 (D4)
unnamed: R6.2, U1.6 (D5)
unnamed: R7.2, U1.7 (D6)
unnamed: R11.1, U1.8 (D7)
unnamed: R10.1, U1.9 (D8)
unnamed: R9.1, U1.10 (D9)
unnamed: R8.1, U1.11 (D10)

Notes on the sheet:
Software-emulated JTAG interface is used to programm MSP430 MCU from ESP32
SPI host controller interface for configuration and data transmission

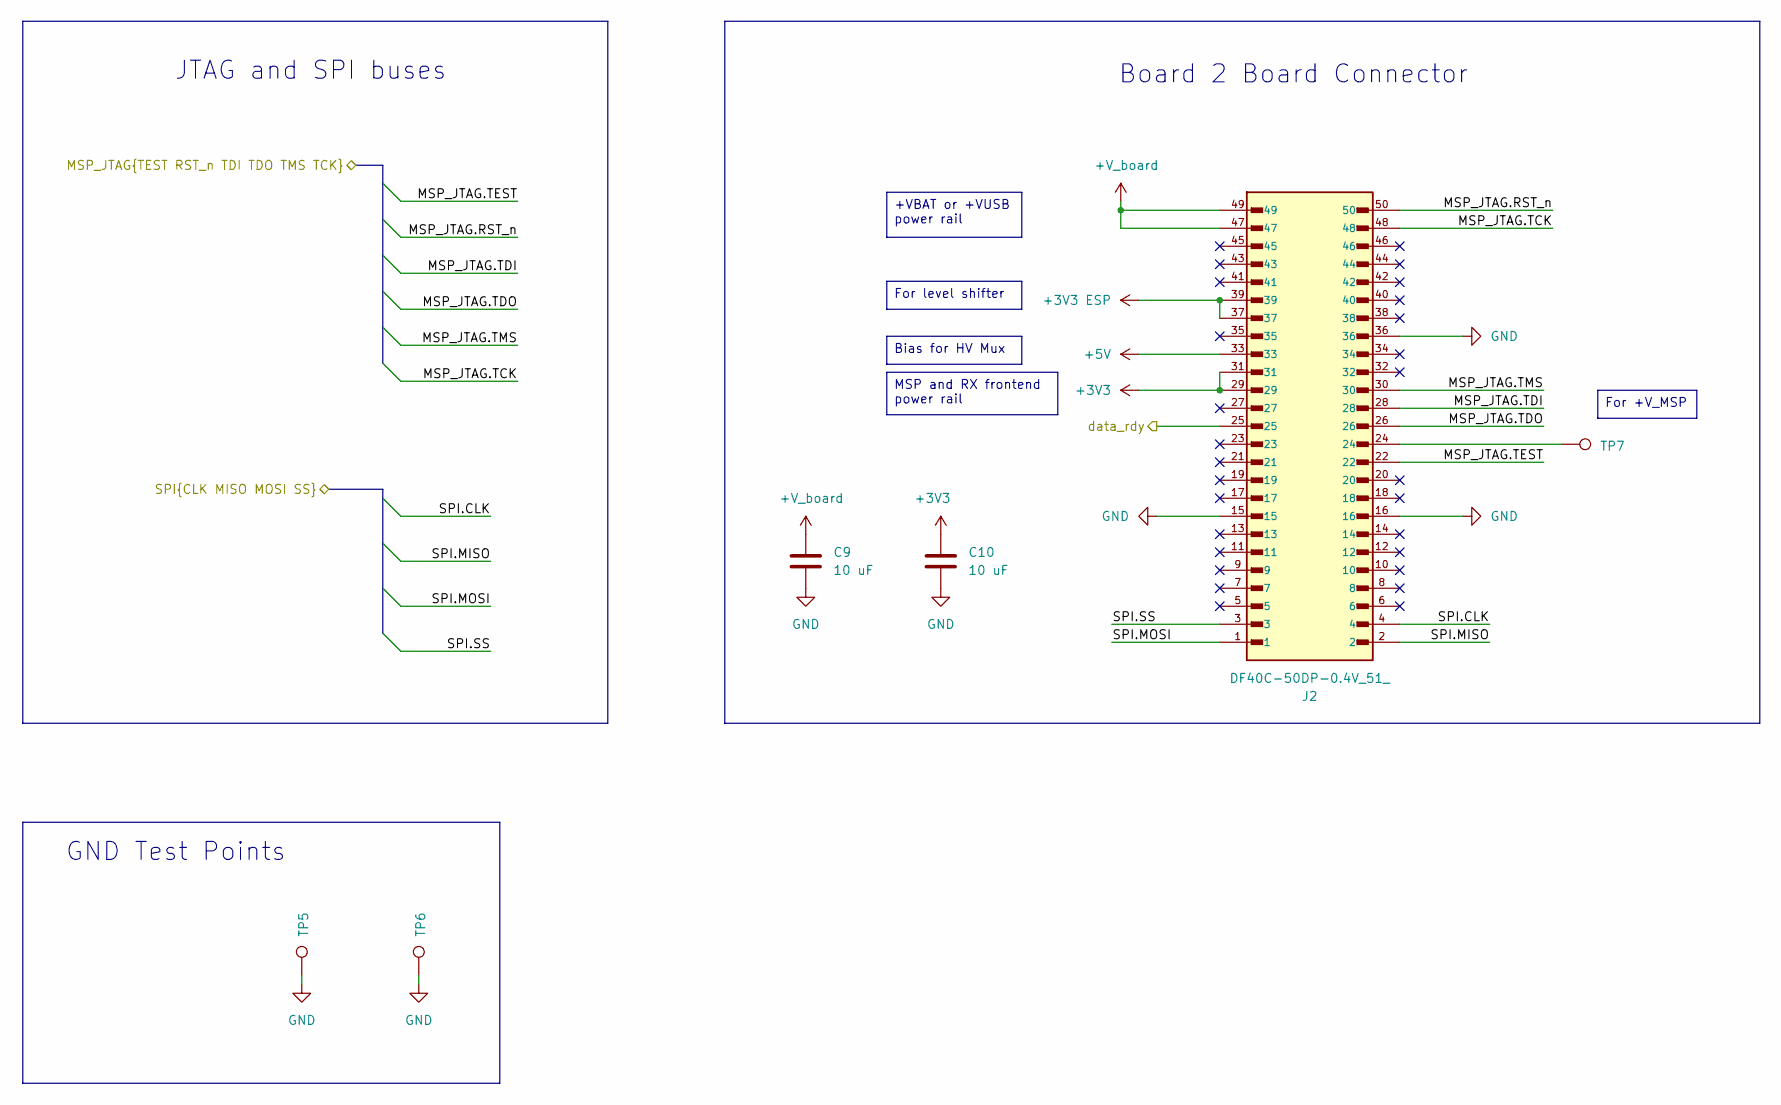
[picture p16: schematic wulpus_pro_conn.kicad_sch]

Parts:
C9, C10: 10 uF; C_0603_1608Metric
J2: DF40C-50DP-0.4V_51_; HIROSE_DF40C-50DP-0.4V_51_; PARTREV 2
TP5, TP6, TP7: TestPoint; TestPoint_Pad_1.0x1.0mm

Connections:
+3V3: C10.1, J2.29, J2.31; also elsewhere on the board
+3V3 ESP: J2.37, J2.39; also elsewhere on the board
+5V: J2.33; also elsewhere on the board
+V_board: C9.1, J2.47, J2.49; also elsewhere on the board
/b2b_connector Sheet/MSP_JTAG.RST_n: J2.50; also elsewhere on the board
/b2b_connector Sheet/MSP_JTAG.TCK: J2.48; also elsewhere on the board
/b2b_connector Sheet/MSP_JTAG.TDI: J2.28; also elsewhere on the board
/b2b_connector Sheet/MSP_JTAG.TDO: J2.26; also elsewhere on the board
/b2b_connector Sheet/MSP_JTAG.TEST: J2.22; also elsewhere on the board
/b2b_connector Sheet/MSP_JTAG.TMS: J2.30; also elsewhere on the board
/b2b_connector Sheet/SPI.CLK: J2.4; also elsewhere on the board
/b2b_connector Sheet/SPI.MISO: J2.2; also elsewhere on the board
/b2b_connector Sheet/SPI.MOSI: J2.1; also elsewhere on the board
/b2b_connector Sheet/SPI.SS: J2.3; also elsewhere on the board
/b2b_connector Sheet/data_rdy: J2.25; also elsewhere on the board
GND: C9.2, C10.2, J2.15, J2.16, J2.36, TP5.1 (1_1), TP6.1 (1_1); also elsewhere on the board
unnamed: J2.24, TP7.1 (1_1)

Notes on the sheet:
JTAG and SPI buses
Board 2 Board Connector
GND Test Points
For +V_MSP
For level shifter
Bias for HV Mux
MSP and RX frontend power rail
+VBAT or +VUSB power rail

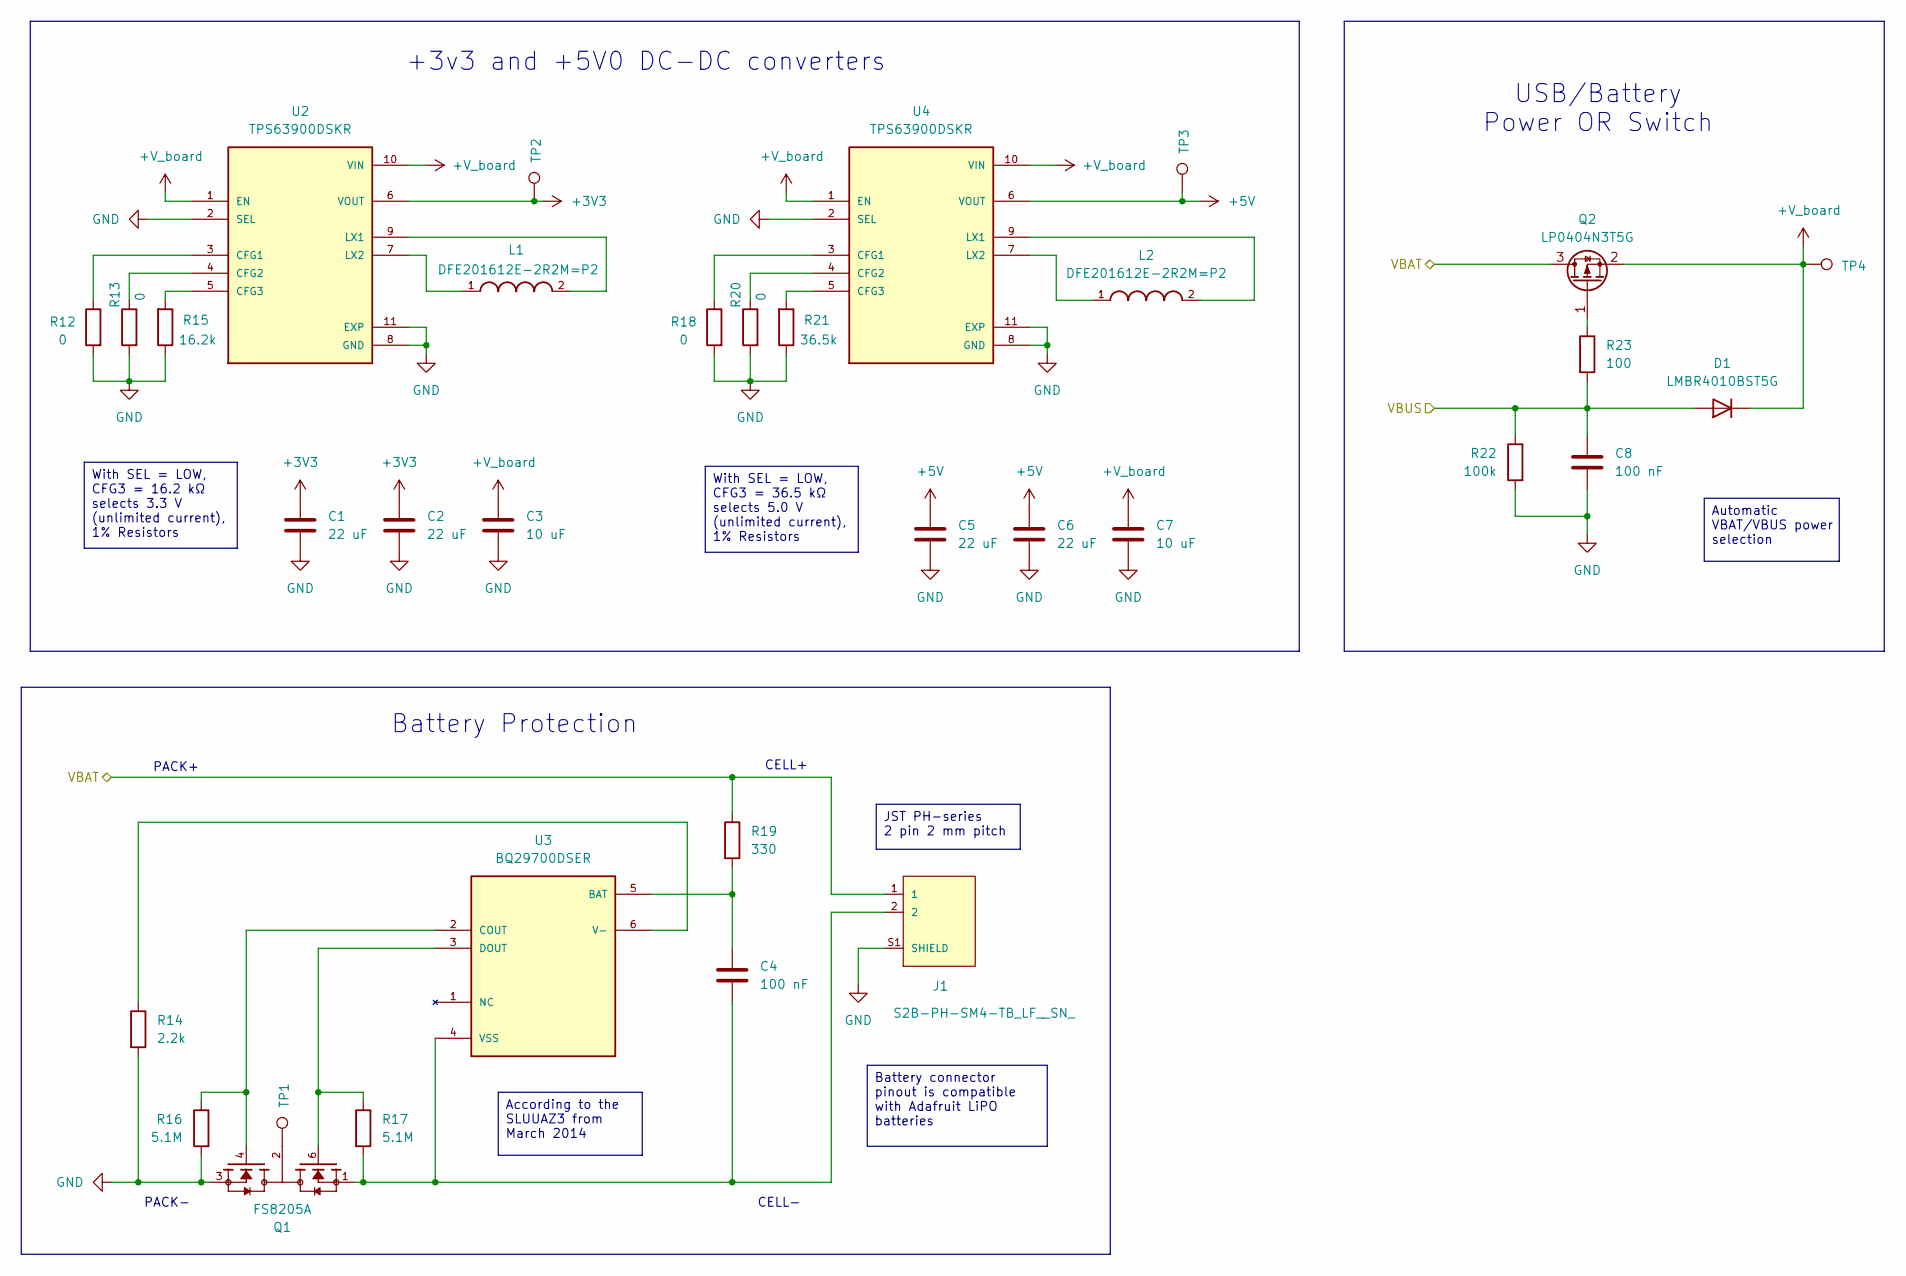
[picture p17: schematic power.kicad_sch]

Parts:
C1, C2, C5, C6: 22 uF; C_0603_1608Metric
C3, C7: 10 uF; C_0603_1608Metric
C4, C8: 100 nF; C_0402_1005Metric
D1: LMBR4010BST5G; D_SOD-882
J1: S2B-PH-SM4-TB_LF__SN_; JST_S2B-PH-SM4-TB_LF__SN_
L1, L2: DFE201612E-2R2M=P2; INDC2016X120N
Q1: FS8205A; SOT95P280X145-6N; PARTREV 1.9
Q2: LP0404N3T5G; SOT-883
R12, R13, R18, R20: 0; R_0402_1005Metric
R14: 2.2k; R_0402_1005Metric
R15: 16.2k; R_0402_1005Metric
R16, R17: 5.1M; R_0402_1005Metric
R19: 330; R_0402_1005Metric
R21: 36.5k; R_0402_1005Metric
R22: 100k; R_0402_1005Metric
R23: 100; R_0402_1005Metric
TP1, TP2, TP3, TP4: TestPoint; TestPoint_Pad_1.0x1.0mm
U2, U4: TPS63900DSKR; IC_TPS63900DSKR; PARTREV D
U3: BQ29700DSER; SON50P150X150X80-6N; PARTREV G

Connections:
+3V3: C1.1, C2.1, TP2.1 (1_1), U2.6 (VOUT); also elsewhere on the board
+5V: C5.1, C6.1, TP3.1 (1_1), U4.6 (VOUT); also elsewhere on the board
+V_board: C3.1, C7.1, D1.1 (K), Q2.2 (S), TP4.1 (1_1), U2.1 (EN), U2.10 (VIN), U4.1 (EN), U4.10 (VIN); also elsewhere on the board
/Power/VBAT: J1.1, Q2.3 (D), R19.1; also elsewhere on the board
/Power/VBUS: C8.1, D1.2 (A), R22.1, R23.2; also elsewhere on the board
GND: C1.2, C2.2, C3.2, C5.2, C6.2, C7.2, C8.2, J1.S1 (SHIELD), J1.S2 (SHIELD), Q1.3, R12.2, R13.2, R14.2, R15.1, R16.2, R18.2, R20.2, R21.1, R22.2, U2.2 (SEL), U2.8 (GND), U2.11 (EXP), U2.14, U2.15, U4.2 (SEL), U4.8 (GND), U4.11 (EXP), U4.14, U4.15; also elsewhere on the board
unnamed: Q1.2, Q1.5, TP1.1 (1_1)
unnamed: Q2.1 (G), R23.1
unnamed: R12.1, U2.3 (CFG1)
unnamed: R13.1, U2.4 (CFG2)
unnamed: R15.2, U2.5 (CFG3)
unnamed: L1.2, U2.9 (LX1)
unnamed: L1.1, U2.7 (LX2)
unnamed: C4.1, R19.2, U3.5 (BAT)
unnamed: Q1.4, R16.1, U3.2 (COUT)
unnamed: Q1.6, R17.1, U3.3 (DOUT)
unnamed: R14.1, U3.6 (V-)
unnamed: C4.2, J1.2, Q1.1, R17.2, U3.4 (VSS)
unnamed: R18.1, U4.3 (CFG1)
unnamed: R20.1, U4.4 (CFG2)
unnamed: R21.2, U4.5 (CFG3)
unnamed: L2.2, U4.9 (LX1)
unnamed: L2.1, U4.7 (LX2)

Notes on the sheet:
CELL-
PACK-
Battery Protection
CELL+
PACK+
+3v3 and +5V0 DC-DC converters
USB/Battery Power OR Switch
With SEL = LOW, CFG3 = 16.2 kΩ selects 3.3 V (unlimited current), 1% Resistors
According to the SLUUAZ3 from March 2014
Battery connector pinout is compatible with Adafruit LiPO batteries
Automatic VBAT/VBUS power selection
With SEL = LOW, CFG3 = 36.5 kΩ selects 5.0 V (unlimited current), 1% Resistors
JST PH-series 2 pin 2 mm pitch

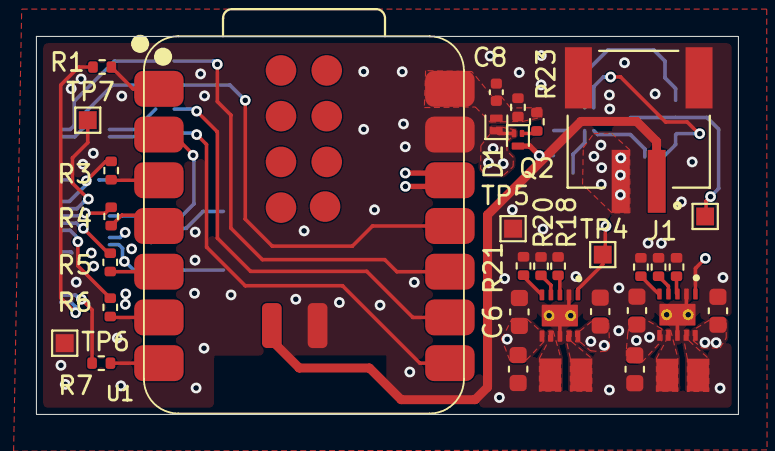
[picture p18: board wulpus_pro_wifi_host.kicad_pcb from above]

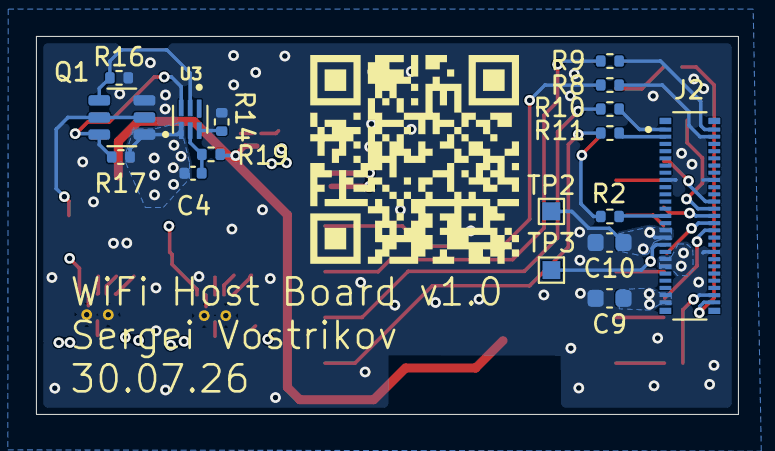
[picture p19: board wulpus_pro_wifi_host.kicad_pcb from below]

Board: 4 copper layers, 39.0 x 21.0 mm, 52 parts (18 on the bottom side), 47 nets.

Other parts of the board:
QR*****: https://github.com/Sergio5714/wulpus-pro; wulpus_pro_qr

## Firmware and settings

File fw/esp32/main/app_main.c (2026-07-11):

/*
Copyright (C) 2025 ETH Zurich. All rights reserved.

Author: Cedric Hirschi, ETH Zurich
        Sergei Vostrikov, GitHub: @Sergio5714

Licensed under the Apache License, Version 2.0 (the "License");
you may not use this file except in compliance with the License.
You may obtain a copy of the License at

    http://www.apache.org/licenses/LICENSE-2.0

Unless required by applicable law or agreed to in writing, software
distributed under the License is distributed on an "AS IS" BASIS,
WITHOUT WARRANTIES OR CONDITIONS OF ANY KIND, either express or implied.
See the License for the specific language governing permissions and
limitations under the License.
*/

/* Wi-Fi Provisioning Manager Example

   This example code is in the Public Domain (or CC0 licensed, at your option.)

   Unless required by applicable law or agreed to in writing, this
   software is distributed on an "AS IS" BASIS, WITHOUT WARRANTIES OR
   CONDITIONS OF ANY KIND, either express or implied.
*/

#include <stdio.h>
#include <string.h>

#include <freertos/FreeRTOS.h>
#include <freertos/task.h>

#include <esp_event.h>
#include <esp_pm.h>
#include <esp_system.h>

#include <driver/gpio.h>
#include <driver/spi_master.h>

#include "bsp.h"
#include "provisioner.h"
#include "mdns_manager.h"
#include "double_reset.h"
#include "commander.h"
#include "sock.h"

#include "helpers.h"

#define LOG_LOCAL_LEVEL ESP_LOG_INFO
#include <esp_log.h>

#define TCP_PORT_MUTEX_TIMEOUT pdMS_TO_TICKS(1000)
#define SPI_MUTEX_TIMEOUT pdMS_TO_TICKS(1000)
#define DATA_READY_TIMEOUT pdMS_TO_TICKS(1000)
#define MSP_BOOT_DELAY_MS 100

static const char *TAG = "main";

socket_instance_t response_socket;
spi_device_handle_t spi = NULL;

TaskHandle_t tcp_server_task_handle = NULL;
TaskHandle_t data_handler_task_handle = NULL;

static QueueHandle_t gpio_evt_queue = NULL;

SemaphoreHandle_t data_ready_semaphore = NULL;
SemaphoreHandle_t tcp_port_mutex = NULL;
SemaphoreHandle_t spi_mutex = NULL;

bool transmits_enabled = false;

uint8_t spi_rx_buffer[CONFIG_WP_DATA_RX_LENGTH + HEADER_LEN];

static void tcp_server_task(void *pvParameters);
static void data_handler_task(void *pvParameters);

static esp_err_t msp_reset_set(bool reset_active)
{
    return gpio_set_level(CONFIG_WP_GPIO_MSP_RST_N, reset_active ? 0 : 1);
}

static void IRAM_ATTR data_ready_handler(void *arg)
{
    uint32_t gpio_num = (uint32_t)arg;
    xQueueSendFromISR(gpio_evt_queue, &gpio_num, NULL);
}

void app_main(void)
{
    ESP_LOGI(TAG, "Entering app_main");
    ESP_ERROR_CHECK(bsp_init());

#if CONFIG_WP_DOUBLE_RESET
    // Check double reset
    bool reset_provisioning = false;
    ESP_ERROR_CHECK(double_reset_start(&reset_provisioning, CONFIG_WP_DOUBLE_RESET_TIMEOUT));
    if (reset_provisioning)
    {
        ESP_LOGI(TAG, "Double reset detected! Provisioning will be reset.");
    }
#endif

#if CONFIG_WP_ENABLE_PM
    // Configure power management (DFS and auto light sleep)
    esp_pm_config_t pm_config = {
        .max_freq_mhz = CONFIG_ESP_DEFAULT_CPU_FREQ_MHZ,
        .min_freq_mhz = 10,
        .light_sleep_enable = true,
    };
    ESP_ERROR_CHECK(esp_pm_configure(&pm_config));
#endif

    esp_log_level_set(TAG, LOG_LOCAL_LEVEL);

    // Initialize provisioner and thus wifi
    ESP_ERROR_CHECK(provisioner_init());

    // Initialize mDNS
    ESP_ERROR_CHECK(mdns_manager_init("wulpus"));
    ESP_ERROR_CHECK(mdns_manager_add("wulpus", MDNS_PROTO_TCP, CONFIG_WP_SOCKET_PORT));

    // Initialize GPIO
    gpio_config_t gpio_cfg = {
        .intr_type = GPIO_INTR_DISABLE,
        .mode = GPIO_MODE_OUTPUT,
        .pin_bit_mask = (1ULL << CONFIG_WP_GPIO_LINK_READY),
        .pull_down_en = GPIO_PULLDOWN_DISABLE,
        .pull_up_en = GPIO_PULLUP_DISABLE,
    };
    ESP_ERROR_CHECK(gpio_config(&gpio_cfg));
    ESP_ERROR_CHECK(gpio_set_level(CONFIG_WP_GPIO_LINK_READY, 0));
    ESP_ERROR_CHECK(gpio_sleep_sel_dis(CONFIG_WP_GPIO_LINK_READY));

    gpio_cfg.intr_type = GPIO_INTR_DISABLE;
    gpio_cfg.mode = GPIO_MODE_OUTPUT_OD;
    gpio_cfg.pin_bit_mask = (1ULL << CONFIG_WP_GPIO_MSP_RST_N);
    gpio_cfg.pull_down_en = GPIO_PULLDOWN_DISABLE;
    gpio_cfg.pull_up_en = GPIO_PULLUP_DISABLE;
    ESP_ERROR_CHECK(gpio_config(&gpio_cfg));
    ESP_ERROR_CHECK(msp_reset_set(true));
    ESP_ERROR_CHECK(gpio_sleep_sel_dis(CONFIG_WP_GPIO_MSP_RST_N));
    ESP_LOGI(TAG, "Reset MSP430 on GPIO %d", CONFIG_WP_GPIO_MSP_RST_N);

    gpio_cfg.intr_type = GPIO_INTR_POSEDGE;
    gpio_cfg.mode = GPIO_MODE_INPUT;
    gpio_cfg.pin_bit_mask = (1ULL << CONFIG_WP_GPIO_DATA_READY);
    ESP_ERROR_CHECK(gpio_config(&gpio_cfg));
    ESP_ERROR_CHECK(gpio_sleep_set_direction(CONFIG_WP_GPIO_DATA_READY, GPIO_MODE_INPUT));
    ESP_ERROR_CHECK(gpio_sleep_set_pull_mode(CONFIG_WP_GPIO_DATA_READY, GPIO_FLOATING));

    // Create semaphore
    gpio_evt_queue = xQueueCreate(10, sizeof(uint32_t));
    if (gpio_evt_queue == NULL)
    {
        ESP_LOGE(TAG, "Failed to create semaphore");
        return;
    }

    data_ready_semaphore = xSemaphoreCreateBinary();
    if (data_ready_semaphore == NULL)
    {
        ESP_LOGE(TAG, "Failed to create semaphore");
        return;
    }

    tcp_port_mutex = xSemaphoreCreateMutex();
    if (tcp_port_mutex == NULL)
    {
        ESP_LOGE(TAG, "Failed to create mutex");
        return;
    }
    spi_mutex = xSemaphoreCreateMutex();
    if (spi_mutex == NULL)
    {
        ESP_LOGE(TAG, "Failed to create mutex");
        return;
    }

    // Create data handler
    xTaskCreate(data_handler_task, "data_handler", CONFIG_WP_HANDLER_STACK_SIZE, NULL, CONFIG_WP_HANDLER_PRIORITY, &data_handler_task_handle);
    if (data_handler_task_handle == NULL)
    {
        ESP_LOGE(TAG, "Failed to create data handler task");
        return;
    }

    // Initialize interrupt
    ESP_ERROR_CHECK(gpio_install_isr_service(0));
    ESP_ERROR_CHECK(gpio_isr_handler_add(CONFIG_WP_GPIO_DATA_READY, data_ready_handler, (void *)CONFIG_WP_GPIO_DATA_READY));

    // Initialize SPI
    spi_bus_config_t spi_cfg = {
        .miso_io_num = CONFIG_WP_SPI_MISO,
        .mosi_io_num = CONFIG_WP_SPI_MOSI,
        .sclk_io_num = CONFIG_WP_SPI_CLK,
        .quadwp_io_num = -1,
        .quadhd_io_num = -1,
        .max_transfer_sz = CONFIG_WP_SPI_MAX_TRANSFER_SIZE,
    };
    spi_device_interface_config_t dev_cfg = {
        .clock_speed_hz = CONFIG_WP_SPI_CLOCK_SPEED,
        .mode = 1,
        .spics_io_num = CONFIG_WP_SPI_CS,
        .queue_size = 3,
        .cs_ena_pretrans = 16,
        .cs_ena_posttrans = 16,
    };
    ESP_ERROR_CHECK(spi_bus_initialize(CONFIG_WP_SPI_INSTANCE - 1, &spi_cfg, SPI_DMA_CH_AUTO));
    ESP_ERROR_CHECK(spi_bus_add_device(CONFIG_WP_SPI_INSTANCE - 1, &dev_cfg, &spi));

    ESP_ERROR_CHECK(gpio_sleep_set_direction(CONFIG_WP_SPI_CLK, GPIO_MODE_OUTPUT));
    ESP_ERROR_CHECK(gpio_sleep_set_pull_mode(CONFIG_WP_SPI_CLK, GPIO_PULLDOWN_ONLY));

    ESP_ERROR_CHECK(gpio_sleep_set_direction(CONFIG_WP_SPI_MOSI, GPIO_MODE_OUTPUT));
    ESP_ERROR_CHECK(gpio_sleep_set_pull_mode(CONFIG_WP_SPI_MOSI, GPIO_PULLDOWN_ONLY));

    ESP_ERROR_CHECK(gpio_sleep_set_direction(CONFIG_WP_SPI_MISO, GPIO_MODE_INPUT));
    ESP_ERROR_CHECK(gpio_sleep_set_pull_mode(CONFIG_WP_SPI_MISO, GPIO_FLOATING));

    ESP_ERROR_CHECK(gpio_sleep_set_direction(CONFIG_WP_SPI_CS, GPIO_MODE_OUTPUT));
    ESP_ERROR_CHECK(gpio_sleep_set_pull_mode(CONFIG_WP_SPI_CS, GPIO_PULLUP_ONLY));

    // Start provisioning
#if CONFIG_WP_DOUBLE_RESET
    ESP_ERROR_CHECK(provisioner_start(reset_provisioning));
#else
    ESP_ERROR_CHECK(provisioner_start(false));
#endif
    ESP_ERROR_CHECK(provisioner_wait());

    // Start but suspend TWT
    provisioner_twt_setup();

    // Start TCP server
    xTaskCreate(tcp_server_task, "tcp_server", CONFIG_WP_SERVER_STACK_SIZE, NULL, CONFIG_WP_SERVER_PRIORITY, &tcp_server_task_handle);
    if (tcp_server_task_handle == NULL)
    {
        ESP_LOGE(TAG, "Failed to create server task");
        return;
    }

    ESP_LOGI(TAG, "Returning from app_main()");
}

static void tcp_server_task(void *pvParameters)
{
    ESP_LOGI(TAG, "TCP server task started");

    uint8_t rx_buffer[CONFIG_WP_SERVER_RX_BUFFER_SIZE];

    socket_instance_t listen_sock = sock_create();
    if (listen_sock.mutex == NULL)
    {
        ESP_LOGE(TAG, "Failed to create listen socket");
        vTaskDelete(NULL);
        return;
    }

    response_socket = sock_create();
    if (response_socket.mutex == NULL)
    {
        ESP_LOGE(TAG, "Failed to create response socket");
        vTaskDelete(NULL);
        return;
    }

    // Initialize and bind listening socket
    ESP_ERROR_CHECK(sock_init(&listen_sock));
    ESP_ERROR_CHECK(sock_listen(&listen_sock, INADDR_ANY, CONFIG_WP_SOCKET_PORT));

    // Initialize response socket
    ESP_ERROR_CHECK(sock_init(&response_socket));

    esp_err_t err = ESP_OK;
    while (1)
    {
        // Accept a connection
        err = sock_accept(&listen_sock, &response_socket);
        if (err != ESP_OK)
        {
            ESP_LOGE(TAG, "Failed to accept connection");
            continue;
        }

        provisioner_twt_suspend(1);
        ESP_ERROR_CHECK(msp_reset_set(false));
        ESP_LOGI(TAG, "Boot MSP430 after TCP connection");
        vTaskDelay(pdMS_TO_TICKS(MSP_BOOT_DELAY_MS));

        // Clear data ready signal
        xSemaphoreTake(data_ready_semaphore, 0);

        bool run = true;
        while (run)
        {
            wulpus_command_header_t recv_header;

            // Receive command from the socket (blocking)
            size_t data_len = sizeof(rx_buffer);
            err = command_recv(&response_socket, &recv_header, rx_buffer, &data_len);
            if (err != ESP_OK)
            {
                ESP_LOGE(TAG, "Failed to receive header");
                run = false;
                break;
            }

            switch (recv_header.command)
            {
            case SET_CONFIG:
                ESP_LOGI(TAG, "Received set config command");

                // FIXME: This could be made tidier in the connection callback, but it's the same in the nRF52 firmware
                ESP_ERROR_CHECK(gpio_set_level(CONFIG_WP_GPIO_LINK_READY, 1));
                ESP_LOGD(TAG, "Link ready signal set");

                // Wait for data ready signal
                if (xSemaphoreTake(data_ready_semaphore, DATA_READY_TIMEOUT) != pdTRUE)
                {
                    ESP_LOGE(TAG, "Failed to take data ready semaphore");
                    break;
                }

                uint8_t spi_tx_buffer[804] = {0};
                memcpy(spi_tx_buffer, rx_buffer, data_len);

                ESP_LOGD(TAG, "Configuration package (%u bytes):", recv_header.data_length);
                for (size_t i = 0; i < recv_header.data_length; i++)
                {
                    ESP_LOGD(TAG, "  0x%02X ", spi_tx_buffer[i]);
                }

                // Send configuration via SPI to the device
                spi_transaction_t tx = {
                    .length = 804 * 8,
                    .tx_buffer = spi_tx_buffer,
                    .rx_buffer = NULL,
                };
                if (xSemaphoreTake(spi_mutex, SPI_MUTEX_TIMEOUT) != pdTRUE)
                {
                    ESP_LOGE(TAG, "Failed to take SPI mutex");
                    break;
                }
                esp_err_t ret = spi_device_transmit(spi, &tx);
                xSemaphoreGive(spi_mutex);
                if (ret != ESP_OK)
                {
                    ESP_LOGE(TAG, "Error occurred during SPI transmission: %s", esp_err_to_name(ret));
                    break;
                }
                else
                {
                    ESP_LOGD(TAG, "Configuration package sent successfully");
                }

                break;
            case GET_DATA:
                ESP_LOGW(TAG, "GET_DATA is not implemented");
                break;
            case PING:
                ESP_LOGI(TAG, "Received ping command");
                // Send response
                wulpus_command_header_t response = {
                    .magic = "wulpus",
                    .command = PONG,
                    .data_length = 4,
                };
                err = command_send(&response_socket, &response, "pong", 4);
                if (err != ESP_OK)
                {
                    ESP_LOGE(TAG, "Failed to send ping response");
                    break;
                }
                break;
            case RESET:
                ESP_LOGI(TAG, "Received reset command");
                // Reset self
                esp_restart();
                break;
            case CLOSE:
                ESP_LOGI(TAG, "Received close command");
                // Exit loop
                run = false;
                break;
            case START_RX:
                ESP_LOGI(TAG, "Received start RX command");
                // Enable transmits
                transmits_enabled = true;

                // By now, MSP could have sent a data ready signal, but we missed it
                if (xSemaphoreTake(data_ready_semaphore, 0) == pdTRUE)
                {
                    // Push dummy event into queue, since handler had to ignore last valid one
                    uint32_t io_num = CONFIG_WP_GPIO_DATA_READY;
                    xQueueSend(gpio_evt_queue, &io_num, 0);
                }

                break;
            case STOP_RX:
                ESP_LOGI(TAG, "Received stop RX command");
                // Disable transmits
                transmits_enabled = false;
                break;
            }

            ESP_LOGI(TAG, "Command %s processed", command_name(recv_header.command));
        }

        transmits_enabled = false;
        ESP_ERROR_CHECK(msp_reset_set(true));
        ESP_LOGI(TAG, "Reset MSP430 after TCP disconnect");

        // Close socket
        err = sock_close(&response_socket);
        if (err != ESP_OK)
        {
            ESP_LOGE(TAG, "Failed to close socket");
        }
        else
        {
            ESP_LOGI(TAG, "Socket closed successfully");
        }

        provisioner_twt_suspend(0);
    }

    vTaskDelete(NULL);
}

static void data_handler_task(void *pvParameters)
{
    ESP_LOGI(TAG, "Data handler task started");

    uint32_t io_num;

    spi_transaction_t rx = {
        .length = CONFIG_WP_DATA_RX_LENGTH * 8,
        .tx_buffer = NULL,
        .rx_buffer = spi_rx_buffer + HEADER_LEN,
    };
    wulpus_command_header_t response = {
        .magic = "wulpus",
        .command = GET_DATA,
        .data_length = CONFIG_WP_DATA_RX_LENGTH,
    };
    memcpy(spi_rx_buffer, &response, HEADER_LEN);

    while (1)
    {
        // Wait for data ready signal
        if (xQueueReceive(gpio_evt_queue, &io_num, portMAX_DELAY) == pdTRUE)
        {
            // Data is ready, handle it here
            ESP_LOGD(TAG, "Data ready signal received on GPIO %lu", io_num);

            // Give data ready semaphore
            xSemaphoreGive(data_ready_semaphore);

            // If socket is open, send data
            // Header: "data <length>"
            // Data: <data>
            if (transmits_enabled & (response_socket.fd >= 0))
            {
                // Read data from the device
                if (xSemaphoreTake(spi_mutex, SPI_MUTEX_TIMEOUT) != pdTRUE)
                {
                    ESP_LOGE(TAG, "Failed to take SPI mutex");
                    continue;
                }
                esp_err_t ret = spi_device_transmit(spi, &rx);
                xSemaphoreGive(spi_mutex);
                if (ret != ESP_OK)
                {
                    ESP_LOGE(TAG, "Error occurred during SPI reception: %s", esp_err_to_name(ret));
                    continue;
                }

                // Send header and data
                ret = sock_send(&response_socket, spi_rx_buffer, CONFIG_WP_DATA_RX_LENGTH + HEADER_LEN);
                if (ret != ESP_OK)
                {
                    ESP_LOGE(TAG, "Failed to send data: %s", esp_err_to_name(ret));
                    transmits_enabled = false;
                    ESP_ERROR_CHECK(msp_reset_set(true));
                    continue;
                }
            }
        }
    }
}

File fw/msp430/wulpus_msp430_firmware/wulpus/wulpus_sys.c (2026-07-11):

/*
 * Copyright (C) 2025 ETH Zurich. All rights reserved.
 *
 * Author: Sergei Vostrikov, ETH Zurich
 *
 * Licensed under the Apache License, Version 2.0 (the "License");
 * you may not use this file except in compliance with the License.
 * You may obtain a copy of the License at
 *
 *      http://www.apache.org/licenses/LICENSE-2.0
 *
 * Unless required by applicable law or agreed to in writing, software
 * distributed under the License is distributed on an "AS IS" BASIS,
 * WITHOUT WARRANTIES OR CONDITIONS OF ANY KIND, either express or implied.
 * See the License for the specific language governing permissions and
 * limitations under the License.
 * 
 * SPDX-License-Identifier: Apache-2.0
 */

#include "wulpus_sys.h"


void getDefaultUsConfig(msp_config_t * msp_config)
{

    msp_config->pllOutFreq = HSPLL_OUT_80_MHZ;
    msp_config->xtalFreq = HSPLL_XTAL_FREQ_8_MHZ;
    msp_config->xtalType = HSPLL_XTAL_CERAMIC_RESONATOR;
    // No buffered xtal clock output
    msp_config->outEnPllXtal = false;


    msp_config->biasImp = BIAS_IMP_2950_OHM;
    msp_config->chargePumpMode = CHARGE_PUMP_NORMAL_MODE;

    msp_config->uupsBiasDelay = UUPS_BIAS_NO_DELAY;

    // Six time marks events (default values)
    msp_config->startPpgCnt = 2500;
    msp_config->turnOnAdcCnt = 25;
    msp_config->startPgaInBiasCnt = 25;
    msp_config->startAdcSamplCnt = 2514;
    msp_config->restartCaptCnt = 937;
    msp_config->captTimeoutCnt = 3750;

    // Extra time events (SW-managed)
    msp_config->startHvMuxRxCnt = 4000;
    msp_config->dcDcTurnOnTime = 1000;


    // Acquisition settings
    msp_config->overSamplRate = SDHS_OVER_SAMPL_RATE_10;
    msp_config->sampleSize = 400;
    msp_config->rxGain = PGA_GAIN_9_0_DB;
    msp_config->measPeriod = 32768;

    // VGA settings
    msp_config->vgaRcPrechargeCycles = 0;
    msp_config->vgaRcGainSlopeWiperCode = 256;

    // TX/RX configurations
    msp_config->txRxConfLen = 0;
//    msp_config->txConfigs[TX_RX_CONF_LEN_MAX];
//    msp_config->rxConfigs[TX_RX_CONF_LEN_MAX];

    // Pulser settins
    msp_config->driveStrength = PPG_NORMAL_DRIVE;

    msp_config->transFreq = 2250000; // Reserved, not used
    msp_config->pulseFreq = 2250000;
    msp_config->pulsesDutyCycle = 50; // 50 %
    msp_config->numPulses = 2;
    msp_config->numStopPulses = 0;
    msp_config->pulserPolarity = PPG_POLARITY_START_WITH_HIGH;
    msp_config->pulserPauseState = PPG_PAUSE_STATE_LOW;

    return;
}

// Extract Uss config from spi RX buffer
// Return 1 if config is valid
bool extractUsConfig(uint8_t * spi_rx, msp_config_t * msp_config)
{
    // Check start byte
    if (spi_rx[0] != START_BYTE_CONF_PACK)
        return 0;

    // Note: The MSP430 cannot access 2-byte words at odd addresses, so the CPU just ignores the lowest bit of word addresses.
    //Therefore, we do here some magic

    msp_config->dcDcTurnOnTime = READ_uint16(spi_rx + 1);
    msp_config->measPeriod     = READ_uint16(spi_rx + 3);
    msp_config->transFreq      = READ_uint32(spi_rx + 5); // Reserved, not used
    msp_config->pulseFreq      = READ_uint32(spi_rx + 9);
    msp_config->numPulses      = READ_uint8(spi_rx + 13);
    msp_config->overSamplRate  = (sdhs_over_sampl_rate_t)READ_uint16(spi_rx + 14);
    msp_config->sampleSize     = READ_uint16(spi_rx + 16);
    msp_config->rxGain         = READ_uint8(spi_rx + 18);
    msp_config->enEnvDetector  = READ_uint8(spi_rx + 19);
    msp_config->txRxConfLen    = READ_uint8(spi_rx + 20);

    if (msp_config->txRxConfLen > TX_RX_CONF_LEN_MAX)
        return 0;

    // Copy the TX RX configs
    uint8_t i;
    for (i = 0; i < (msp_config->txRxConfLen); i++)
    {
        msp_config->txConfigs[i] = READ_uint16(spi_rx + 21 + 4*i);
        msp_config->rxConfigs[i] = READ_uint16(spi_rx + 23 + 4*i);
    }

    uint8_t offset = 21 + 4*(msp_config->txRxConfLen);

    // Copy the data from the Advanced settings section
    msp_config->startHvMuxRxCnt         = READ_uint16(spi_rx + offset);
    msp_config->startPpgCnt             = READ_uint16(spi_rx + offset + 2);
    msp_config->turnOnAdcCnt            = READ_uint16(spi_rx + offset + 4);
    msp_config->startPgaInBiasCnt       = READ_uint16(spi_rx + offset + 6);
    msp_config->startAdcSamplCnt        = READ_uint16(spi_rx + offset + 8);
    msp_config->restartCaptCnt          = READ_uint16(spi_rx + offset + 10);
    msp_config->captTimeoutCnt          = READ_uint16(spi_rx + offset + 12);
    msp_config->vgaRcPrechargeCycles    = READ_uint16(spi_rx + offset + 14);
    msp_config->vgaRcGainSlopeWiperCode = READ_uint16(spi_rx + offset + 16);

    return 1;
}

// Check the first byte and check if restart should be done.
bool isRestartCondition(uint8_t * spi_rx)
{
    // Check for restart byte
    if (spi_rx[0] != START_BYTE_RESTART)
    {
        return 0;
    }

    return 1;
}
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

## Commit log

2026-06-29 Updating spressif SDK, migrating to XIAO C6 board
2026-07-02 bugfix: alwazs enable preamp power switch at init
    [wulpus_sys.c]
2026-07-03 esp32: updating readme, small fixes in wifi project
2026-07-09 Added Apache-2.0 license headers to ESP32 firmware source files and Python support scripts.
    [300fps-nopm.csv]
2026-07-11 Upload photos, updated documentation of the project, added PCBWAY link
2026-07-11 bugfix: always enable preamp power switch at init
    [wulpus_sys.c]
2026-07-11 docs: upload photos, update documentation of the project, added PCBWAY link
2026-07-18 Adding a template for host_pc KiCAD project
    [wulpus_pro_wifi_host.kicad_pcb, wulpus_pro_wifi_host.kicad_sch]
2026-07-18 Linked Footprint and Symbols libraries, added to the KiCAD project
    [wulpus_pro_wifi_host.kicad_sch]
2026-07-18 Added Hirose host connector, made PCB template
    [wulpus_pro_wifi_host.kicad_pcb, wulpus_pro_wifi_host.kicad_sch]
2026-07-20 Added main ICs to the schematics and layout template
    [b2b_connector.kicad_sch, esp32.kicad_sch, power.kicad_sch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]
2026-07-22 Added hierarchical shets, signals for esp32 and battery protector ref schematic
    [esp32.kicad_sch, power.kicad_sch, wulpus_pro_wifi_host.kicad_sch]
2026-07-23 Partially added DC-DCs
    [power.kicad_sch]
2026-07-26 Add PCBWAY KiCAD design rules
2026-07-26 Updated footprints, mapped 3D models, added layerstack, partial placement and layout
    [esp32.kicad_sch, power.kicad_sch, wulpus_pro_conn.kicad_sch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]
2026-07-27 Added preliminary layout
    [power.kicad_sch, wulpus_pro_wifi_host.kicad_pcb]
2026-07-29 Finished layout, fixed DRCs
    [wulpus_pro_conn.kicad_sch, wulpus_pro_wifi_host.kicad_pcb]
2026-07-30 Changed cap footprints to 0603
    [esp32.kicad_sch, power.kicad_sch, wulpus_pro_conn.kicad_sch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]
2026-08-01 Fixed BOM, added jobset file, regenerated fabrication outputs
    [esp32.kicad_sch, power.kicad_sch, wulpus_pro_conn.kicad_sch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]
2026-08-02 Added out capacitors for DC-DCs, regenerated fabrication files
    [power.kicad_sch, wulpus_pro_conn.kicad_sch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]
2026-08-03 Add draft of the fab (assembly) layers
    [wulpus_pro_wifi_host-B_Cu.gbl, wulpus_pro_wifi_host-B_Fab.gbr, wulpus_pro_wifi_host-B_Mask.gbs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]
2026-08-22 Update layer stack, clean up jobset file, PCB and schematics, regenerated outputs
    [wulpus_pro_wifi_host-B_Cu.gbl, wulpus_pro_wifi_host-B_Fab.gbr, wulpus_pro_wifi_host-B_Mask.gbs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]
2026-08-22 Document WiFi host PCB, hardware licenses, and private KiCad library
